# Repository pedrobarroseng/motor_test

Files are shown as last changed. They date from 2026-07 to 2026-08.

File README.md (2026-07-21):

# Motor Test — ESC Controller with Nokia 5110 Display

An Arduino-based Electronic Speed Controller (ESC) testing platform designed to drive and monitor brushless motors through a potentiometer interface, with real-time telemetry displayed on a Nokia 5110 LCD. The system supports both unidirectional and bidirectional ESC configurations and implements a layered safety architecture to prevent motor damage and unintended behavior.

---

## Table of Contents

- [Overview](#overview)
- [Hardware Requirements](#hardware-requirements)
- [Pin Mapping](#pin-mapping)
- [Dependencies and Libraries](#dependencies-and-libraries)
- [System Architecture](#system-architecture)
  - [Safety Layer](#safety-layer)
  - [Menu and ESC Selection](#menu-and-esc-selection)
  - [Motor Arming Sequence](#motor-arming-sequence)
  - [Control Loop](#control-loop)
- [Signal Mapping](#signal-mapping)
- [Display States](#display-states)
- [Serial Output](#serial-output)
- [Data Acquisition](#data-acquisition)
- [Known Limitations](#known-limitations)

---

## Overview

This firmware implements a bench-test environment for brushless motor ESCs. Rather than relying on a standard RC transmitter, the system uses an analog potentiometer as a manual throttle source, translating its position into PWM microsecond signals recognized by standard ESC protocols.

The project is structured around two core operational modes:

| Mode | Description | PWM Range |
|---|---|---|
| **Unidirectional** | Full-range throttle from minimum to maximum | 1000 – 1900 µs |
| **Bidirectional** | Symmetric control around a neutral center point | 1000 – 2000 µs |

---

## Hardware Requirements

| Component | Description |
|---|---|
| Arduino Mega 2560 (or compatible) | Main microcontroller |
| Nokia 5110 LCD (PCD8544) | 84×48 pixel monochrome display |
| ESC (Electronic Speed Controller) | Unidirectional or bidirectional type |
| Brushless DC Motor | Compatible with the chosen ESC |
| 10 kΩ Potentiometer | Analog throttle control input |
| 2× Momentary Push Buttons | ESC type selection and system reset |

> **Note:** The pin assignments used in this project (especially pins 22 and 23 for buttons) are specific to boards with extended digital I/O, such as the Arduino Mega. Adaptation is required for boards like the Arduino Uno.

---

## Pin Mapping

| Pin | Role | Mode |
|---|---|---|
| `A0` | Potentiometer (throttle) | `INPUT` (analog) |
| `8` | ESC signal (PWM output) | `OUTPUT` via `Servo` library |
| `9` | Nokia 5110 — RST | `OUTPUT` |
| `10` | Nokia 5110 — CE (chip enable) | `OUTPUT` |
| `11` | Nokia 5110 — DC (data/command) | `OUTPUT` |
| `12` | Nokia 5110 — DIN (data in) | `OUTPUT` |
| `13` | Nokia 5110 — CLK (clock) | `OUTPUT` |
| `22` | ESC type selection button | `INPUT_PULLUP` |
| `23` | System reset button | `INPUT_PULLUP` |

---

## Dependencies and Libraries

### 1. `SPI.h` *(Arduino Built-in)*
The **Serial Peripheral Interface** library provides communication between the Arduino and SPI-compatible peripherals. In this project, it serves as the underlying transport layer for the Nokia 5110 display driver, handling the synchronous clock and data lines (CLK and DIN).

### 2. `Adafruit_GFX.h` *(Adafruit Industries)*
A hardware-agnostic **graphics abstraction library** that provides a common API for drawing primitives — text, rectangles, lines, and filled shapes — across a wide range of display hardware. It decouples the drawing logic from the specific display driver, enabling portability. This project uses it to render text, the progress bar, and layout separators on the Nokia 5110 screen.

> Install via Arduino Library Manager: `Adafruit GFX Library`

### 3. `Adafruit_PCD8544.h` *(Adafruit Industries)*
The hardware-specific driver for the **Philips PCD8544 display controller**, which powers the Nokia 5110 LCD module. It implements the low-level SPI command protocol for the PCD8544, including contrast control, display initialization, and memory-mapped pixel buffering. The `display.display()` call flushes the internal buffer to the physical screen.

> Install via Arduino Library Manager: `Adafruit PCD8544 Nokia 5110 LCD library`

### 4. `Servo.h` *(Arduino Built-in)*
The **Servo library** generates PWM signals in the range of 1000 to 2000 microseconds — the standard pulse-width protocol used by RC ESCs and servos. The `motor.writeMicroseconds()` method provides precise pulse-width control, which is more suitable for ESC calibration than the angular `motor.write()` method.

---

## System Architecture

### Safety Layer

The firmware implements three distinct safety mechanisms:

**1. Potentiometer Disconnection Detection**

At the end of each `loop()` iteration, the current ADC reading (`leituraAtual`) is stored as `leituraInicial`. On the next iteration, if the absolute difference between these two readings exceeds 512 (half the ADC range of 0–1023), the system enters a locked state (`sistemaTravado = true`), cutting the motor signal and displaying an error message. This detects sudden, physically implausible jumps in the potentiometer value — characteristic of a disconnected or broken analog input.

```
|leituraAtual - leituraInicial| ≥ 512  →  LOCK
```

**2. Motor Arming Requirement**

The motor will not respond to the potentiometer until `motorArmado` is set to `true`. This flag is only set when the potentiometer ADC reading falls below `50` (approximately 0% throttle), ensuring the operator physically zeros the throttle before gaining control. This prevents a motor from starting at an arbitrary throttle value upon boot.

**3. Bidirectional Neutral Lock**

For bidirectional ESCs, an additional flag (`sinalLiberado`) requires the operator to center the potentiometer near the neutral position (ADC reading within ±30 of 512) before free control is granted. Until this condition is met, the firmware forces a 1500 µs signal regardless of the actual potentiometer reading. This prevents abrupt direction reversals on ESCs that require a neutral-pass initialization.

---

### Menu and ESC Selection

The `setup()` function enters a blocking `while` loop that implements a two-action button interface using a single button (`PIN_BUTTON_ESC`), distinguished by press duration:

| Interaction | Duration | Action |
|---|---|---|
| Short press | < 800 ms | Toggle ESC type (uni/bi-directional) |
| Long press | ≥ 1000 ms | Confirm selection and exit menu |

The confirmation progress is visualized on the display as a fill-bar that grows from left to right over the 1000 ms hold window, computed using Arduino's `map()` and `constrain()` functions:

```cpp
int progresso = map(millis() - tempoSegurando, 0, 1000, 0, 84);
progresso = constrain(progresso, 0, 84);
```

The number `84` corresponds to the horizontal pixel width of the Nokia 5110 display. A debounce delay of 20 ms is applied at the end of each menu cycle.

---

### Motor Arming Sequence

After menu confirmation, the firmware performs the ESC initialization handshake:

- **Unidirectional:** sends a 1000 µs signal (minimum throttle).
- **Bidirectional:** sends a 1500 µs signal (neutral/center).

This step is required by most commercial ESCs, which expect to receive the minimum (or neutral) signal on startup before accepting throttle commands.

---

### Control Loop

The main `loop()` follows this execution order on each iteration:

```
1. Read potentiometer (ADC 0–1023)
2. Check reset button → call setup() if pressed
3. Check disconnection delta → lock if exceeded
4. Send CSV header once (first iteration only)
5. If locked:
   - Hold motor at minimum signal
   - Display error screen
   - Report LOCKED state via serial
6. If not locked:
   a. Check arming condition (ADC < 50)
   b. If armed:
      - Map ADC to PWM microseconds
      - Map ADC to percentage
      - Apply neutral lock (bidirectional only)
      - Update display
      - Write PWM to ESC
      - Send CSV telemetry line via serial
   c. If not armed:
      - Hold minimum/neutral signal
      - Display arming instruction
      - Report DISARMED state via serial
7. Store current ADC as reference for next iteration
8. Delay 10 ms
```

---

## Signal Mapping

The `map()` function performs a linear interpolation from the ADC domain to the PWM and percentage domains.

### The PWM RC Protocol

Both modes follow the **standard hobby PWM RC protocol**, which originated in the 1970s with radio-controlled systems and has since been widely adopted by the ESC industry for drones, aircraft, and robotics. In this protocol, the ESC does not interpret positive or negative voltages — it measures only the **duration of each pulse** in microseconds and maps that duration to a motor command according to its internal firmware:

```
1000 µs ←————————————— 1500 µs ————————————→ 2000 µs
   |                       |                       |
minimum                  center                 maximum
```

The physical meaning of each point depends entirely on the ESC type. The same electrical pulse of 1000 µs means "stopped" on a unidirectional ESC and "maximum reverse" on a bidirectional one — the signal is identical; only the ESC's internal firmware interpretation differs.

It is worth noting that more modern ESC protocols such as DSHOT, Oneshot, and Multishot use different signal formats and ranges. This bench targets specifically the standard PWM RC protocol, which remains the most widely supported across commercial ESC models.

---

### Unidirectional ESC

| Variable | Input Range | Output Range | Resolution |
|---|---|---|---|
| `sinalFinal` (PWM) | 0 – 1023 | 1000 – 1900 µs | ~0.88 µs per ADC step |
| `porcentagem` | 0 – 1023 | 0 – 100 % | ~0.098% per ADC step |

The usable PWM range is **900 µs** (1000 to 1900 µs). The maximum is intentionally capped at 1900 µs rather than 2000 µs as a safety margin for bench testing — this means the ESC never receives the absolute maximum pulse, operating at approximately 95% of its full rated range. The practical effect of this cap is greater control resolution: each 1% of potentiometer travel corresponds to ~9 µs of PWM variation, giving the operator finer granularity over the motor speed.

---

### Bidirectional ESC

| Variable | Input Range | Output Range | Resolution |
|---|---|---|---|
| `sinalFinal` (PWM) | 0 – 1023 | 1000 – 2000 µs | ~0.98 µs per ADC step |
| `porcentagem` | 0 – 1023 | -100 – 100 % | ~0.195% per ADC step |

The full 1000–2000 µs range is used to preserve the **symmetric range around the 1500 µs neutral point**:

```
1000 µs → -100% (maximum reverse)   distance from neutral: 500 µs
1500 µs →    0% (neutral / stopped) distance from neutral:   0 µs
2000 µs → +100% (maximum forward)   distance from neutral: 500 µs
```

The ESC internally computes the deviation from neutral (`pulse - 1500 µs`) to determine direction and magnitude. Both directions are therefore symmetric in power delivery.

A throttle reading of -100% producing a PWM of 1000 µs may appear counterintuitive — a lower number representing higher reverse power. This is not a design flaw but a direct consequence of the RC PWM protocol convention. This behavior is deliberately preserved in the telemetry display to maintain full traceability between raw PWM values and physical ESC behavior.

Compared to the unidirectional mode, each side of the bidirectional range spans only 500 µs, meaning each 1% of potentiometer travel corresponds to ~5 µs of PWM variation — making the control more sensitive per unit of potentiometer movement.

---

## Display States

The Nokia 5110 renders five distinct screens throughout the program lifecycle:

| State | Trigger | Content |
|---|---|---|
| **Splash Screen** | Boot | `"MOTOR TEST"` and `"ESC Bench"`, shown for 2 seconds |
| **ESC Selection Menu** | `setup()` while-loop | Mode selector with progress bar |
| **Arming Prompt** | Motor not yet armed | Instructions to zero the potentiometer |
| **Neutral Lock Warning** | Bidirectional, center not reached | Current percentage, separator line, and target PWM |
| **Telemetry Screen** | Normal operation | ESC type, throttle %, separator, PWM value, separator, raw ADC |

---

## Serial Output

During normal operation, the firmware transmits data at **115200 baud** in CSV format. A header line is sent once per session immediately after the menu selection, followed by one data line per loop iteration (~10 ms interval).

### CSV Format

```
timestamp_ms,pwm_us,adc_raw,throttle_pct,esc_type,system_state
```

| Field | Description | Example |
|---|---|---|
| `timestamp_ms` | Time since boot in milliseconds (`millis()`) | `8040` |
| `pwm_us` | PWM signal sent to the ESC in microseconds | `1450` |
| `adc_raw` | Raw ADC reading from the potentiometer (0–1023) | `461` |
| `throttle_pct` | Mapped throttle percentage (0–100 or -100–100) | `45` |
| `esc_type` | Selected ESC mode | `UNI` or `BI` |
| `system_state` | Current system state | `ARMED`, `DISARMED`, `WAITING_NEUTRAL`, `LOCKED` |

### Example Output

```
timestamp_ms,pwm_us,adc_raw,throttle_pct,esc_type,system_state
8040,1000,0,0,UNI,ARMED
8109,1450,461,45,UNI,ARMED
8178,1523,535,52,UNI,ARMED
```

---

## Data Acquisition

This project includes a Python-based data acquisition and analysis pipeline for collecting and visualizing ESC test data.

### Requirements

```
pyserial
matplotlib
pandas
```

Install with:

```bash
pip install pyserial matplotlib pandas --break-system-packages
```

### Project Structure

```
motor_test/
├── Motor_test/
│   ├── Motor_test.ino       # Arduino firmware
│   ├── aquisicao.py         # Serial data acquisition script
│   └── analise.py           # Data analysis and plot generation
├── data/
│   ├── raw/                 # Auto-generated CSV files (gitignored)
│   └── samples/             # Curated representative CSVs and PNGs for publication
└── .gitignore
```

### Standardized Test Protocols

To ensure reproducible and comparable results across different ESC models, the following test protocols are recommended:

| Test | Description | Applicable Modes |
|---|---|---|
| **Manual Ramp** | Gradually rotate the potentiometer from 0% to 100% (or -100% to +100%) over ~5–10 seconds | UNI, BI |
| **Step (Positive)** | Hold at neutral for ~3 seconds, then abruptly rotate to maximum forward throttle | UNI, BI |
| **Step (Negative)** | Hold at neutral for ~3 seconds, then abruptly rotate to maximum reverse throttle | BI only |

### Usage

**Step 1 — Flash the firmware** using the Arduino IDE, then close the Serial Monitor.

**Step 2 — Run acquisition:**
```bash
python3 Motor_test/aquisicao.py
```
The script connects to `/dev/ttyUSB0` at 115200 baud, saves data to `data/raw/teste_YYYY-MM-DD_HH-MM-SS.csv`, and prints each line to the terminal. Press `Ctrl+C` to stop and close the serial port cleanly.

**Step 3 — Run analysis:**
```bash
python3 Motor_test/analise.py
```

The analysis script supports two modes:

**Mode 1 — Individual plot:** Enter the CSV filename and a label (e.g. `UNI` or `BI`). The script generates a three-panel plot (PWM, throttle %, and ADC raw vs. time) with the label in each subplot title, and saves it as a PNG alongside the CSV.

**Mode 2 — Comparison plot:** Enter two CSV filenames and their respective labels. The script aligns both datasets to start at t=0, clips them to the same duration, and overlays them in a three-panel comparative plot. The output PNG is saved as `comparacao_<file1>_vs_<file2>.png`.

> **Note:** Only `ARMED` state data is plotted in both modes. `DISARMED`, `WAITING_NEUTRAL`, and `LOCKED` rows are automatically filtered out before plotting.

**Step 4 — Curate results:**
Copy the most representative CSVs and PNGs from `data/raw/` to `data/samples/` for use in publications and repository sharing.

---

## Known Limitations

- **`setup()` called from `loop()`:** Invoking `setup()` manually from within `loop()` upon a reset button press is non-standard Arduino practice. While functional, it does not perform a true hardware reset and may leave certain hardware states (e.g., the `Servo` timer) in an inconsistent condition. A hardware reset via the `RESET` pin or a watchdog timer would be a more robust alternative.

- **`sistemaTravado` is irreversible:** Once the disconnection lock is triggered, there is no in-firmware path to clear it without a physical reset. This is intentional as a safety measure but should be documented for the operator.

- **No EEPROM persistence:** The ESC type selected in the menu is not stored in non-volatile memory. Every power cycle requires the operator to re-select the mode.

- **Single serial port dependency:** The Python acquisition script and the Arduino IDE Serial Monitor cannot access the port simultaneously. The Serial Monitor must be closed before running `aquisicao.py`.

- **Open-loop architecture:** The bench operates in open loop — it generates and records PWM command signals but has no feedback from the motor or ESC. It characterizes the command behavior of the system, not the mechanical response. Sensor integration (e.g. current sensor, RPM sensor) would be required for closed-loop characterization.

- **Bidirectional neutral dead zone:** The neutral lock mechanism requires the potentiometer ADC reading to be within ±30 of 512 before control is released. This creates a small dead zone around the center position in bidirectional mode, which may cause minor oscillations at the start of tests that begin near neutral. This behavior is visible in the telemetry data and should be accounted for when interpreting bidirectional test results.

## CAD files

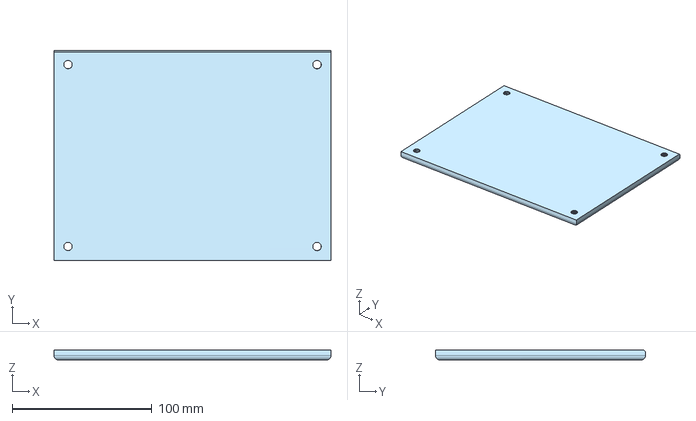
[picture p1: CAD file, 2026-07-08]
CAD/Part Studio 1 - Part 1.step
198.0 x 150.0 x 7.00 mm

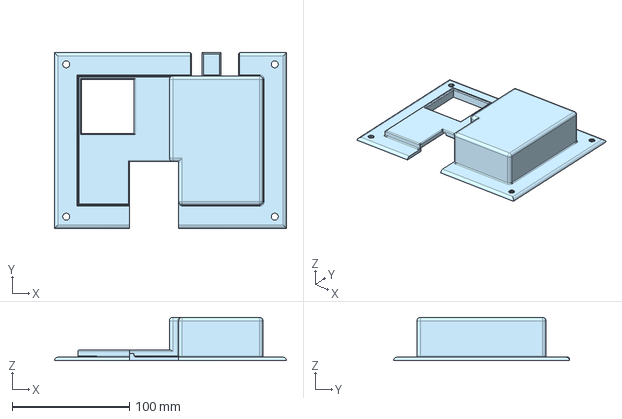
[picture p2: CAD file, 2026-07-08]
CAD/Part Studio 1 - Part 2.step
198.0 x 150.0 x 37.0 mm

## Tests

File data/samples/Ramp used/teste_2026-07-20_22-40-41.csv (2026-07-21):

timestamp_ms | pwm_us | adc_raw | throttle_pct | esc_type | system_state
9406 | 1000 | 1023 | 0 | UNI | DISARMED
9478 | 1000 | 1023 | 0 | UNI | DISARMED
9549 | 1000 | 1023 | 0 | UNI | DISARMED
9621 | 1000 | 1023 | 0 | UNI | DISARMED
9693 | 1000 | 1023 | 0 | UNI | DISARMED
9763 | 1000 | 1023 | 0 | UNI | DISARMED
9835 | 1000 | 1023 | 0 | UNI | DISARMED
9907 | 1000 | 1023 | 0 | UNI | DISARMED
9978 | 1000 | 1023 | 0 | UNI | DISARMED
10050 | 1000 | 1023 | 0 | UNI | DISARMED
10122 | 1000 | 1023 | 0 | UNI | DISARMED
10193 | 1000 | 1023 | 0 | UNI | DISARMED
10265 | 1000 | 1023 | 0 | UNI | DISARMED
10337 | 1000 | 1023 | 0 | UNI | DISARMED
10408 | 1000 | 1023 | 0 | UNI | DISARMED
10480 | 1000 | 1023 | 0 | UNI | DISARMED
10552 | 1000 | 1023 | 0 | UNI | DISARMED
10624 | 1000 | 1023 | 0 | UNI | DISARMED
10694 | 1000 | 1023 | 0 | UNI | DISARMED
10766 | 1000 | 1023 | 0 | UNI | DISARMED
10838 | 1000 | 1023 | 0 | UNI | DISARMED
10909 | 1000 | 1023 | 0 | UNI | DISARMED
10981 | 1000 | 1023 | 0 | UNI | DISARMED
11053 | 1000 | 1023 | 0 | UNI | DISARMED
11124 | 1000 | 1023 | 0 | UNI | DISARMED
11196 | 1000 | 1023 | 0 | UNI | DISARMED
11268 | 1000 | 1023 | 0 | UNI | DISARMED
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

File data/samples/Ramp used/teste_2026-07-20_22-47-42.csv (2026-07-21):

timestamp_ms | pwm_us | adc_raw | throttle_pct | esc_type | system_state
8449 | 1500 | 0 | -100 | BI | WAITING_NEUTRAL
8526 | 1500 | 0 | -100 | BI | WAITING_NEUTRAL
8604 | 1500 | 0 | -100 | BI | WAITING_NEUTRAL
8682 | 1500 | 0 | -100 | BI | WAITING_NEUTRAL
8761 | 1500 | 0 | -100 | BI | WAITING_NEUTRAL
8839 | 1500 | 0 | -100 | BI | WAITING_NEUTRAL
8916 | 1500 | 0 | -100 | BI | WAITING_NEUTRAL
8994 | 1500 | 0 | -100 | BI | WAITING_NEUTRAL
9072 | 1500 | 0 | -100 | BI | WAITING_NEUTRAL
9150 | 1500 | 0 | -100 | BI | WAITING_NEUTRAL
9229 | 1500 | 0 | -100 | BI | WAITING_NEUTRAL
9307 | 1500 | 0 | -100 | BI | WAITING_NEUTRAL
9384 | 1500 | 0 | -100 | BI | WAITING_NEUTRAL
9462 | 1500 | 0 | -100 | BI | WAITING_NEUTRAL
9540 | 1500 | 0 | -100 | BI | WAITING_NEUTRAL
9619 | 1500 | 0 | -100 | BI | WAITING_NEUTRAL
9697 | 1500 | 0 | -100 | BI | WAITING_NEUTRAL
9775 | 1500 | 0 | -100 | BI | WAITING_NEUTRAL
9852 | 1500 | 0 | -100 | BI | WAITING_NEUTRAL
9930 | 1500 | 0 | -100 | BI | WAITING_NEUTRAL
10008 | 1500 | 0 | -100 | BI | WAITING_NEUTRAL
10087 | 1500 | 0 | -100 | BI | WAITING_NEUTRAL
10165 | 1500 | 0 | -100 | BI | WAITING_NEUTRAL
10243 | 1500 | 0 | -100 | BI | WAITING_NEUTRAL
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

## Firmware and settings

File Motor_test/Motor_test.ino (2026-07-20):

/*
 * ================================================================
 *  Motor Test - ESC Controller with Nokia 5110 Display
 *  Hardware: Arduino Mega 2560
 * ================================================================
 *  SERIAL OUTPUT (115200 baud) - CSV format:
 *  timestamp_ms, pwm_us, adc_raw, throttle_pct, esc_type, system_state
 *
 *  system_state values:
 *    DISARMED        -> Motor not yet armed (waiting for zero throttle)
 *    WAITING_NEUTRAL -> Bidirectional ESC waiting for center position
 *    ARMED           -> Normal operation
 *    LOCKED          -> Potentiometer disconnection detected (safety lock)
 * ================================================================
 */

#include <SPI.h>
#include <Adafruit_GFX.h>
#include <Adafruit_PCD8544.h>
#include <Servo.h>

// -- Pin definitions --------------------------------------------
const int PIN_POTENCIOMETRO = A0;
const int PIN_ESC           = 8;
const int PIN_BUTTON_ESC    = 22;
const int PIN_BUTTON_RESET  = 23;

// -- Display: CLK, DIN, DC, CE, RST -----------------------------
Adafruit_PCD8544 display = Adafruit_PCD8544(13, 12, 11, 10, 9);

// -- Motor ------------------------------------------------------
Servo motor;

// -- ESC configuration ------------------------------------------
// 0 = unidirectional | 1 = bidirectional
int escType = 0;

// -- Safety layer -----------------------------------------------
int  leituraInicial  = 0;
bool sistemaTravado  = false;
bool motorArmado     = false;
bool sinalLiberado   = false;

// -- Menu state ------------------------------------------------
bool menuConfirmado  = false;
unsigned long tempoSegurando = 0;
bool botaoAnterior   = false;

// -- Serial header flag ----------------------------------------
bool headerEnviado = false;

// ==============================================================
void setup() {
  Serial.begin(115200);

  pinMode(PIN_POTENCIOMETRO, INPUT);
  pinMode(PIN_BUTTON_ESC,    INPUT_PULLUP);
  pinMode(PIN_BUTTON_RESET,  INPUT_PULLUP);

  // -- Display init ---------------------------------------------
  display.begin();
  display.setContrast(55);
  display.clearDisplay();
  display.setTextSize(1);
  display.setTextColor(BLACK);
  display.setCursor(10, 15);
  display.println("MOTOR TEST");
  display.setCursor(10, 28);
  display.println("ESC Bench");
  display.display();
  delay(2000);

  // -- ESC Type selection menu --
  menuConfirmado = false;
  botaoAnterior  = false;
  tempoSegurando = 0;

  while (!menuConfirmado) {
    bool estadoBotao = (digitalRead(PIN_BUTTON_ESC) == LOW);

    // Rising edge: button just pressed
    if (estadoBotao && !botaoAnterior) {
      tempoSegurando = millis();
    }

    // Falling edge: button just released (short press -> toggle)
    if (!estadoBotao && botaoAnterior) {
      if (millis() - tempoSegurando < 800) {
        escType = !escType;
      }
      tempoSegurando = 0;
    }

    // Held for 1 second -> confirm
    if (estadoBotao && tempoSegurando > 0 && (millis() - tempoSegurando >= 1000)) {
      menuConfirmado = true;
    }

    botaoAnterior = estadoBotao;

    // -- Menu display --
    display.clearDisplay();
    display.setCursor(0, 0);
    display.println("Escolha o ESC:");
    display.setCursor(0, 15);
    display.print(escType == 0 ? "> Uni-dir" : "  Uni-dir");
    display.setCursor(0, 28);
    display.print(escType == 1 ? "> Bi-dir " : "  Bi-dir ");

    if (estadoBotao && tempoSegurando > 0) {
      int progresso = map(millis() - tempoSegurando, 0, 1000, 0, 84);
      progresso = constrain(progresso, 0, 84);
      display.drawRect(0, 40, 84, 8, BLACK);
      display.fillRect(0, 40, progresso, 8, BLACK);
    } else {
      display.setCursor(0, 40);
      display.print("segure p/ conf.");
    }

    display.display();
    delay(20);
  }

  // -- ESC arming signal --
  motor.attach(PIN_ESC);
  motor.writeMicroseconds(escType == 0 ? 1000 : 1500);

  // -- Reset safety state --
  leituraInicial = analogRead(PIN_POTENCIOMETRO);
  sistemaTravado = false;
  motorArmado    = false;
  sinalLiberado  = false;
  headerEnviado  = false;

  delay(2000);
}

// =============================================================
void loop() {
  int leituraAtual = analogRead(PIN_POTENCIOMETRO);

  // -- Reset button --
  if (digitalRead(PIN_BUTTON_RESET) == LOW) {
    motor.writeMicroseconds(escType == 0 ? 1000 : 1500);
    delay(200); // debounce
    setup();
    return;
  }

  // -- Disconnection detection --
  if (abs(leituraAtual - leituraInicial) >= 512) {
    sistemaTravado = true;
  }

  // == CSV header (sent once per session, after menu) ========
  if (!headerEnviado) {
    Serial.println("timestamp_ms,pwm_us,adc_raw,throttle_pct,esc_type,system_state");
    headerEnviado = true;
  }

  // == LOCKED state ==========================================
  if (sistemaTravado) {
    motor.writeMicroseconds(1000);

    display.clearDisplay();
    display.setCursor(0, 10);
    display.println("!! ERRO !!");
    display.setCursor(0, 22);
    display.println("Pot desconectado");
    display.setCursor(0, 34);
    display.println("Pressione reset");
    display.display();

    // Report locked state
    enviarCSV(1000, leituraAtual, 0, "LOCKED");

  // == NORMAL state ==========================================
  } else {

    // -- Arming condition: throttle must be at zero first --
    if (leituraAtual < 50) {
      motorArmado = true;
    }

    if (motorArmado) {
      int sinalFinal;
      int porcentagem;

      //-- Signal mapping per ESC type--
      if (escType == 0) {
        sinalFinal  = map(leituraAtual, 0, 1023, 1000, 1900);
        porcentagem = map(leituraAtual, 0, 1023, 0, 100);
        sinalLiberado = true;
      } else {
        sinalFinal  = map(leituraAtual, 0, 1023, 1000, 2000);
        porcentagem = map(leituraAtual, 0, 1023, -100, 100);
        if (abs(leituraAtual - 512) < 30) {
          sinalLiberado = true;
        }
      }

      display.clearDisplay();
      display.setTextSize(1);
      display.setTextColor(BLACK);

      // -- WAITING NEUTRAL (bidirectional only) --
      if (escType == 1 && !sinalLiberado) {
        sinalFinal = 1500;

        display.setCursor(0, 0);
        display.println("Bi-dir: va ao");
        display.println("centro (0%)");
        display.setCursor(0, 20);
        display.print("Pot: "); display.print(porcentagem); display.println("%");
        display.println("--------------");
        display.setCursor(0, 35);
        display.print("PWM alvo: "); display.print(sinalFinal);
        display.display();

        motor.writeMicroseconds(sinalFinal);
        enviarCSV(sinalFinal, leituraAtual, porcentagem, "WAITING_NEUTRAL");

      // -- ARMED: normal telemetry --
      } else {
        display.setCursor(0, 0);
        display.print(escType == 0 ? "ESC Uni-dir" : "ESC Bi-dir");
        display.setCursor(0, 10);
        display.print("Pot: "); display.print(porcentagem); display.println("%");
        display.println("--------------");
        display.setCursor(0, 25);
        display.print("PWM: "); display.print(sinalFinal); display.println("us");
        display.println("--------------");
        display.setCursor(0, 40);
        display.print("ADC: "); display.print(leituraAtual);
        display.display();

        motor.writeMicroseconds(sinalFinal);
        enviarCSV(sinalFinal, leituraAtual, porcentagem, "ARMED");
      }

    // -- DISARMED: waiting for zero throttle --
    } else {
      motor.writeMicroseconds(escType == 0 ? 1000 : 1500);

      display.clearDisplay();
      display.setCursor(0, 8);
      display.println("Gire o pot");
      display.println("para o minimo");
      display.println("(esquerda)");
      display.println("para armar.");
      display.display();

      enviarCSV(escType == 0 ? 1000 : 1500, leituraAtual, 0, "DISARMED");
    }
  }

  leituraInicial = leituraAtual;
  delay(10);
}

// ==============================================================
// Helper: sends one CSV line over serial
// Format: timestamp_ms,pwm_us,adc_raw,throttle_pct,esc_type,system_state
// ==============================================================
void enviarCSV(int pwm, int adcRaw, int pct, const char* state) {
  Serial.print(millis());       Serial.print(",");
  Serial.print(pwm);            Serial.print(",");
  Serial.print(adcRaw);         Serial.print(",");
  Serial.print(pct);            Serial.print(",");
  Serial.print(escType == 0 ? "UNI" : "BI"); Serial.print(",");
  Serial.println(state);
}

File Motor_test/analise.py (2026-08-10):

import matplotlib.pyplot as plt
import pandas as pd
import numpy as np

mode = input("Mode? (1 = individual, 2 = comparison): ")

if mode == '1':

    file = input("Enter the CSV file name (e.g., teste_2026-07-0-19_14-30-00.csv): ")
    label = input("Label for the plot (e.g., UNI, BI): ").title()
    df = pd.read_csv(f"data/raw/{file}")
    df = df[df['system_state'] == 'ARMED']
    df['timestamp_ms'] = df['timestamp_ms'] - df['timestamp_ms'].iloc[0]

    # Linear fit of pwm_us vs adc_raw (output vs input at the same instant).
    # This measures how linear the firmware's ADC->PWM mapping is, NOT how
    # steady the manual potentiometer actuation was — hand tremor changes the
    # shape of the curve over time, but not the point-by-point proportionality
    # between adc_raw and pwm_us, unless the firmware mapping itself is non-linear.
    r_squared = np.corrcoef(df['adc_raw'], df['pwm_us'])[0, 1] ** 2

    # Printed with more decimal places so the exact value is available for the
    # paper text (the plot legend below only shows 3 decimals for readability).
    print(f"[{label}] R² (pwm_us vs adc_raw) = {r_squared:.5f}")

    fig, (ax1, ax2, ax3) = plt.subplots(3, 1, figsize=(10, 8))

    # R² added to the legend as a quantitative linearity metric, replacing
    # purely qualitative claims like "smooth" or "no noticeable jitter".
    ax1.plot(df['timestamp_ms'], df['pwm_us'], label=f'{label} (R² = {r_squared:.3f})')
    ax1.set_ylabel('PWM (us)')
    ax1.set_xlabel('Timestamp (ms)')
    ax1.set_title(f'PWM vs Timestamp - {label}')
    ax1.legend()

    ax2.plot(df['timestamp_ms'], df['throttle_pct'], label=label)
    ax2.set_ylabel('Throttle (%)')
    ax2.set_xlabel('Timestamp (ms)')
    ax2.set_title(f'Throttle vs Timestamp - {label}')
    ax2.legend()

    ax3.plot(df['timestamp_ms'], df['adc_raw'], label=label)
    ax3.set_ylabel('ADC Raw')
    ax3.set_xlabel('Timestamp (ms)')
    ax3.set_title(f'ADC Raw vs Timestamp - {label}')
    ax3.legend()

    plt.tight_layout()  # Avoids overlap between subplots
    plt.savefig(f"data/raw/{file.replace('.csv', '.png')}")  # Saves the plot as PNG
    plt.show()  # Displays the plot on screen

elif mode == '2':
    file1 = input("Enter the first CSV file name (e.g., teste_2026-07-0-19_14-30-00.csv): ")
    file2 = input("Enter the second CSV file name (e.g., teste_2026-07-0-19_14-30-00.csv): ")

    label1 = input("Label for the first file (e.g., UNI): ").title()
    label2 = input("Label for the second file (e.g., BI): ").title()

    df1 = pd.read_csv(f"data/raw/{file1}")
    df2 = pd.read_csv(f"data/raw/{file2}")

    df1 = df1[df1['system_state'] == 'ARMED']
    df2 = df2[df2['system_state'] == 'ARMED']

    df1['timestamp_ms'] = df1['timestamp_ms'] - df1['timestamp_ms'].iloc[0]
    df2['timestamp_ms'] = df2['timestamp_ms'] - df2['timestamp_ms'].iloc[0]

    # Same linear-fit logic as mode 1, computed separately for each file.
    # Calculated here (before the max_time cut below) so each R² reflects
    # its own full ARMED segment, not just the time window shared by both files.
    r2_1 = np.corrcoef(df1['adc_raw'], df1['pwm_us'])[0, 1] ** 2
    r2_2 = np.corrcoef(df2['adc_raw'], df2['pwm_us'])[0, 1] ** 2
    print(f"[{label1}] R² (pwm_us vs adc_raw) = {r2_1:.5f}")
    print(f"[{label2}] R² (pwm_us vs adc_raw) = {r2_2:.5f}")

    max_time = min(df1['timestamp_ms'].max(), df2['timestamp_ms'].max())
    df1 = df1[df1['timestamp_ms'] <= max_time]
    df2 = df2[df2['timestamp_ms'] <= max_time]

    fig, (ax1, ax2, ax3) = plt.subplots(3, 1, figsize=(10, 8))

    # R² added to each label as a quantitative linearity metric.
    ax1.plot(df1['timestamp_ms'], df1['pwm_us'], label=f'{label1} (R² = {r2_1:.3f})')
    ax1.plot(df2['timestamp_ms'], df2['pwm_us'], label=f'{label2} (R² = {r2_2:.3f})')
    ax1.set_ylabel('PWM (us)')
    ax1.set_xlabel('Timestamp (ms)')
    ax1.set_title('PWM Comparison vs Timestamp')
    ax1.legend()

    ax2.plot(df1['timestamp_ms'], df1['throttle_pct'], label=label1)
    ax2.plot(df2['timestamp_ms'], df2['throttle_pct'], label=label2)
    ax2.set_ylabel('Throttle (%)')
    ax2.set_xlabel('Timestamp (ms)')
    ax2.set_title('Throttle Comparison vs Timestamp')
    ax2.legend()

    ax3.plot(df1['timestamp_ms'], df1['adc_raw'], label=label1)
    ax3.plot(df2['timestamp_ms'], df2['adc_raw'], label=label2)
    ax3.set_ylabel('ADC Raw')
    ax3.set_xlabel('Timestamp (ms)')
    ax3.set_title('Raw ADC Comparison vs Timestamp')
    ax3.legend()

    plt.tight_layout()
    plt.savefig(f"data/raw/comparison_{file1[:22]}_vs_{file2[:22]}.png")
    plt.show()

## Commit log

2026-04-08 feat: implementa travas de segurança e modo dual ESC
2026-04-15 Logica com o botão para teste no lab
2026-04-25 Atalizando a estrura do código e resolvendo o bug para os ESCs BI-dir
    [Motor_test.ino]
2026-05-20 up: código do motor atualizado e README normatizado
2026-07-08 Adicionando o CAD da case
    [Part Studio 1 - Part 1.step, Part Studio 1 - Part 2.step]
2026-07-20 Adicionando a parte de coleta de dados em python, o código fonte atualizado e a documentação atualizada
2026-07-21 Atualizações nos códigos em python e dados extraídos da bancada
    [teste_2026-07-20_22-40-41.csv, teste_2026-07-20_22-47-42.csv, teste_2026-07-20_22-56-14.csv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]
2026-08-10 Mundanças para o ingles no arquivo de analise
    [teste_2026-07-20_19-32-53.csv, teste_2026-07-20_19-44-04.csv, teste_2026-07-20_19-59-26.csv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]
2026-08-10 Atualização dos arquivos
    [teste_2026-07-20_19-32-53.csv, teste_2026-07-20_19-44-04.csv, teste_2026-07-20_19-59-26.csv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]
